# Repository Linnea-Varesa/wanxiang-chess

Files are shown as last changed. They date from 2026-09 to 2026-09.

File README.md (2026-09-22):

> **当前执行基线（2026-09-22）**：第一阶段直接做 3×3 九线圈识别验证。第一批一次采购完整 3×3 所需器件，霍尔先买 3～4 个做位置层对照；验证按单线圈→三线圈→九线圈推进，M3 截止 2026-10-31。8×8 材料待 M3 通过后决定。

# 万象实体互动桌：国际象棋路线

当前版本正在从“触点身份棋盘”调整为“无触点静态识别优先”的原型：棋子底部优先测试无电池被动身份标签，棋盘表面保持平滑，通过小规模样片验证身份和格位。ESP32-S3 负责设备控制、快照、屏幕和通信，手机或后续微信小程序负责棋局、合法性、本地 AI 和语音指导。DS2431G/GA + 触点保留为电气基线和备用路线。自动移子只预留接口，今年不做实物交付。

摄像头识别、64 格 RFID 阵列、自动移子和量产结构不属于当前验收范围。

本目录是新方向的正式工程目录。目标是用一年时间，由两人小组（每人每周约 6 小时）完成一台个人可稳定使用的国际象棋实体互动桌，并在稳定性、成本和安全性达到要求后评估小规模量产。

## 当前冻结的首年范围

- 国际象棋，8×8 棋盘，Android 优先。
- 首版先完成：棋子唯一身份、静态格位识别、平滑棋盘、棋局状态、BLE 同步、AI 走法和语音/屏幕提示。
- 先用玩家手动放置验证识别；系统必须能用 UID 和格位复核结果。
- 自动移动、让路和多棋子同步只保留机械接口与研究记录，不列入 2026 年交付。
- Android 仅作为当前工程调试端；微信小程序保留为后期交互候选，协议不绑定某一种前端。
- 首批实验预算约 2000–3000 元。已有万用表、焊接工具、可调电源和基础机械工具，不重复采购。

## 资料边界

[`references/original_handoff/`](references/original_handoff/) 和 [`references/original_archive/`](references/original_archive/) 是历史交接资料和原始压缩包的只读参考副本。原工程第一版以五子棋、摄像头 ArUco 和单 XY 演示为主；新工程以本 README 和 [`docs/`](docs/) 中的决策为准。

完整目录用途和文件路径索引见 [`docs/18_目录与文件索引.md`](docs/18_目录与文件索引.md)。当前硬件决策以 [`docs/25_工程重整与一次性采购决策_2026-09-22.md`](docs/25_工程重整与一次性采购决策_2026-09-22.md) 为准。文档之间的引用使用相对于引用文件的路径；历史参考副本保留原路径，不作为当前工程接口。

面向指导老师的当前阶段汇报、采购、分工和周计划集中在 [`teacher_report/`](teacher_report/)，首份总览为 [`teacher_report/00_阶段汇报_2026-09-18.md`](teacher_report/00_阶段汇报_2026-09-18.md)。

## 先做什么

1. 根据 [`mechanical/pieces/3mf模型核验_2026-09-18.md`](mechanical/pieces/3mf模型核验_2026-09-18.md) 先打印少量兵、马、车，测量底座和身份盘空间。
2. 用第一批九路线圈、PN5180、SLIX2 标签和 3×3 非金属面板做身份、相邻格隔离和读距验证；先接单线圈，再扩三线圈和九线圈。
3. 同步搭建与前端无关的规则模拟器和 BLE 协议，不等待全盘硬件。
4. 形成“识别 → 合法走法 → AI → 语音/屏幕 → 玩家手动移动 → 复核”的闭环。
5. 识别稳定后，再为后续自动移子保留机械和通信接口，不在今年采购完整运动机构。

## 文档索引

- [`docs/01_项目目标与范围.md`](docs/01_项目目标与范围.md)
- [`docs/02_一年路线图与阶段验收.md`](docs/02_一年路线图与阶段验收.md)
- [`docs/03_工作分解与两人分工.md`](docs/03_工作分解与两人分工.md)
- [`docs/04_系统架构与接口.md`](docs/04_系统架构与接口.md)
- [`docs/05_棋子身份识别实验.md`](docs/05_棋子身份识别实验.md)
- [`docs/06_嘉立创EDA与电路计划.md`](docs/06_嘉立创EDA与电路计划.md)
- [`docs/07_固件开发计划.md`](docs/07_固件开发计划.md)
- [`docs/08_Android与AI计划.md`](docs/08_Android与AI计划.md)
- [`docs/09_自动移子与避障研究.md`](docs/09_自动移子与避障研究.md)
- [`docs/10_预算采购与风险.md`](docs/10_预算采购与风险.md)
- [`docs/11_量产前准备.md`](docs/11_量产前准备.md)
- [`docs/12_资料索引与决策记录.md`](docs/12_资料索引与决策记录.md)
- [`docs/13_三个月无视觉身份棋盘方案.md`](docs/13_三个月无视觉身份棋盘方案.md)
- [`docs/14_开发板与器件选型核验.md`](docs/14_开发板与器件选型核验.md)
- [`docs/15_参考产品说明书分析.md`](docs/15_参考产品说明书分析.md)
- [`docs/16_触点对自动移子影响与身份器件决策.md`](docs/16_触点对自动移子影响与身份器件决策.md)
- [`docs/17_开发板选择与系统分层.md`](docs/17_开发板选择与系统分层.md)
- [`docs/18_目录与文件索引.md`](docs/18_目录与文件索引.md)
- [`docs/19_无触点身份与自行移动路线评估.md`](docs/19_无触点身份与自行移动路线评估.md)
- [`docs/20_屏幕与微信小程序后置方案.md`](docs/20_屏幕与微信小程序后置方案.md)
- [`docs/22_3x3识别定位试验BOM评审_2026-09-20.md`](docs/22_3x3识别定位试验BOM评审_2026-09-20.md)

## 状态约定

文档中的“计划”不是“已验证”。每项工作必须记录负责人、日期、实测数据、结论和下一步。首年不把零碎时间计入承诺产能。

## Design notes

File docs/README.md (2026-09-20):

# 文档目录

本目录保存项目决策、技术方案、路线、采购核验和参考产品分析。总目录见 [`18_目录与文件索引.md`](18_目录与文件索引.md)；当前无视觉主线见 [`13_三个月无视觉身份棋盘方案.md`](13_三个月无视觉身份棋盘方案.md)；新提交的 3×3 识别定位 BOM 评审见 [`22_3x3识别定位试验BOM评审_2026-09-20.md`](22_3x3识别定位试验BOM评审_2026-09-20.md)。

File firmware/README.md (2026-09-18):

# ESP32-S3 固件

PlatformIO 工程，运行在棋盘主控上。编译配置见 [`platformio.ini`](platformio.ini)，源码见 [`src/`](src/)，身份扫描入口见 [`src/identity_grid.cpp`](src/identity_grid.cpp)。

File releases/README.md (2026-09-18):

# 发布与演示包

预留 Android APK、ESP32 固件 bin、演示脚本、录屏和版本归档。当前尚未生成正式发布包。

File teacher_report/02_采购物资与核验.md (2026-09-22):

# 采购物资与参数核验（当前版）

时间 tag：`2026-09-22T21:00+08:00`

## 采购决定

今天下单第一批完整 3×3 九线圈验证系统。器材一次采购到位，安装和验证按单线圈、三线圈、九线圈分阶段执行。目标是 2026-10-31 前完成 M3 九线圈静态快照；3×3 通过后才决定 8×8 全棋盘材料。

## 第一批采购

| 模块 | 型号/规格 | 数量 | 用途 | 核验重点 |
|---|---|---:|---|---|
| 主控 | ESP32-S3-DevKitC-1-N8R8 或可靠 N16R8 | 1+1备用 | 扫描调度、显示、USB/BLE | 丝印、GPIO、USB、3.3 V |
| 读卡 | PN5180 成品开发板 | 1 | 读取 ISO15693 标签 UID | SPI、外接天线/匹配接口 |
| 棋格线圈 | ANT-24-V1 | 9+1备用 | 九个格位采样 | 电感、Q、谐振和邻格耦合 |
| RF切换 | RF-SW-9CH-V1 | 1 | 把一个读头逐格接到九线圈 | 是否已经装 9 个 RF 继电器、是否双线 DPDT |
| RF继电器 | G6K-2F-RF-V DC5 | 9（仅切换板不含时购买） | 切换 PN5180 两条 RF 线 | 完整后缀、线圈电压、触点形式 |
| 继电器控制 | SN74HC595PWR + ULN2803CDWR | 各2 | 输出选择位和驱动 5 V 继电器 | 3.3 V 输入吸合测试 |
| 霍尔位置层 | DRV5032 + D6×2 mm 磁铁 | 3～4 + 6～8 | 验证有/无棋子，不识别身份 | 感应距离、输出类型、去抖 |
| 霍尔输入扩展 | SN74HC165PWR | 2 | 9 路霍尔预留输入 | 串行位序、上拉和电平 |
| 棋子身份 | ISO15693 SLIX2 小标签 | 12～15 | 9 枚使用，余量备用 | 优先 12～16 mm；读距和磁体影响 |
| 显示 | ST7789 2 inch SPI | 1+1备用 | 现场显示通道、UID、状态 | 实物引脚和逻辑电平 |
| 电源/匹配/连接 | 5 V 4 A、3.3 V模块、C0G电容、电阻、U.FL、短同轴、非金属面板、端子 | 1套 | 供电、调谐和搭建 | 共地、反灌、RF走线 |
| 测量 | NanoVNA-H4 | 1或借用 | 测谐振、匹配、串扰 | 校准夹具和重复性 |

## 分阶段验证

- **M0（9月27日前）**：所有第一批物料到货清点，完成丝印、接口、电源和缺件记录。
- **M1（10月4日前）**：单标签和单线圈连续读取，屏幕和电脑网页显示日志。
- **M2（10月18日前）**：三线圈逐格读取，3～4 路霍尔与 UID 结果对照。
- **M3（10月31日前）**：九线圈安装完成，重复采集 3×3 静态快照，记录空读、串读、成功率和扫描耗时。

阶段门只控制“如何接入和验证”，不再触发第二次 3×3 架构采购。M3 后再决定 8×8 材料。

详细清单见 [`../hardware/bom/3x3首批一次采购清单_2026-09-22.md`](../hardware/bom/3x3首批一次采购清单_2026-09-22.md)。

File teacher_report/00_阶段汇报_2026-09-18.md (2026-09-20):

# 万象实体互动桌阶段汇报

**时间 tag：`2026-09-18T18:45+08:00`**
**汇报周期：`2026-09-19` 至 `2026-12-31`**  
**项目类型：两人个人学习与娱乐原型，国际象棋，Android 优先**

## 一、目前进度

项目已经从“空想和资料收集”进入“识别路线重新评估、采购准备、首个 3D 打印测试待启动”阶段。当前已经完成：

- 在 `F:/projects/wanxiang-chess` 建立正式工程目录、目录说明和相对路径索引。
- 阅读并保存参考产品说明书、历史交接文件和原始工程；历史资料仅作参考。
- 启动路线修正：不采用视觉识别作为主链路，优先验证平滑棋盘、被动身份标签和静态格位识别；原 `DS2431G/GA + 触点` 方案降为电气基线。
- 保留 `ESP32-S3` 作为主控，负责读头、快照、屏幕和 BLE；自动移子状态机只预留接口，前端不绑定 Android，微信小程序保留为后置候选。
- 已读取用户提供的 `chess.3mf`，确认其棋盘插板约 204×204×3 mm，平均格距约 25.5 mm，棋子底座约 17.85–21.41 mm。
- 建立固件身份扫描原型、身份记录格式、2×2/4×4 实验方案、采购清单和三个月验收清单。
- 已补充具体采购检索：ESP32-S3-N16R8 预焊针版、PN532 V3、ILI9341 屏幕、3 mm 亚克力样片、N42 圆片磁体和 5 V 3 A 电源；检索词与验收条件见 [`../hardware/bom/采购检索与核验_2026-09-20.md`](../hardware/bom/采购检索与核验_2026-09-20.md)。
- 已有基础工具：万用表、焊接工具、可调电源和基础机械工具。

尚未完成且不应在汇报中表述为已完成：

- 没有真实开发板、标签/读头样品或 DS2431 接触座上的电气验证。
- 没有 2×2 或 4×4 实物识别成功率数据。
- ESP32 固件尚未在真实板卡上编译烧录。
- Android 尚未形成可安装 APK，BLE 仍处于协议和模型准备阶段。
- 8×8 全盘身份阵列、自动移子、多棋子让路和量产结构均未立项实现。

## 二、项目方向

目标是做一台个人使用的实体国际象棋互动桌：棋子本身不带电池、不放蓝牙模块和复杂电路板；棋子底部使用被动身份标签，棋盘表面保持平滑，先由小规模样片验证“哪个格位出现哪个 UID”。主控负责快照、屏幕和通信，后续由 Android 或微信小程序负责棋局和 AI。

产品闭环为：

```text
棋子 UID/格位样片 → 读头/位置层 → ESP32-S3 → BLE/屏幕
→ 合法性判断/AI/难度/语音 → 玩家手动放置 → 再次扫描确认
```

首版重点是证明“无电池棋子在平滑棋盘上能被稳定识别并定位”。自动移子不在 2026 年范围内，运动机构只保留接口和后续研究记录。

## 三、预计技术方案

### 1. 棋子身份

当前首选先测试 13.56 MHz、ISO14443A 的 `NTAG213` 小标签；它不需要电池，UID 可作为棋子身份。`DS2431G+U/GA+U` 与触点保留为静止棋子电气基线，因为触点会增加滑动阻力、磨损和落位约束。

先按 `chess.3mf` 打印兵、马、车各 1–2 枚，底部使用可更换身份盘。先比较空白盘、NFC 标签盘和磁编码盘，再决定是否改永久结构。

### 2. 棋盘主控和识别

首选 `ESP32-S3-DevKitC-1-N8R8` 两块，一主一备。它负责 NFC/位置层读头、快照、BLE 和屏幕接口；AI 不放在 ESP32 上。首轮只做 2×2 无触点样片。

### 3. 软件和屏幕

Android 先作为调试端；微信小程序保留为后期交互候选。两者都不直接绑定硬件，先共用 BLE/串口消息协议。棋盘加入 2.8 inch ILI9341 SPI 屏幕，显示回合、走法、连接、扫描和故障状态；AI 仍在手机/电脑运行。

### 4. 自动移子后续边界

主路线不使用暴露触点。棋盘表面保持平滑，自动移子将来可采用下方磁力耦合，但 2026 年不采购、不搭建实物运动机构；多棋子同步、让路和避障列为后续研究。

## 四、截至年底的目标

年底目标是一个可向老师演示的“识别与软件闭环原型”，而不是完整量产产品：

- 硬件：完成 3D 打印棋子样品、单枚被动标签识别、2×2 无触点定位样片，争取扩展到 4×4；屏幕由 ESP32-S3 驱动显示基本状态。
- 软件：完成棋子 UID 登记、棋局模型、BLE 快照协议、Android 棋盘视图、AI 走法、至少 3 档难度和语音提示。
- 演示：从局面加载开始，完成“AI 指定走法 → 屏幕/语音提示 → 玩家手动放置 → UID/位置确认 → 继续对局”，并演示一次放错棋子或格位的错误提示。
- 文档：保留采购凭证、接线图、UID 登记表、实验数据、问题清单和每周总结。

不列入年底硬性承诺：8×8 实物全盘、多个棋子同时移动、联网对战、量产设计和最终外壳。

## 五、主要风险和判断点

1. **标签读距和相邻格串读**：先用 2×2 数据判断是否继续扩大；不能只凭一次读到 UID 就认为方案可行。
2. **磁力与身份件互扰**：先测 NFC 标签、磁体和读头距离，再决定底部结构。
3. **3D 打印尺寸误差**：先打印兵、马、车各少量样品，测量底面和格距，不直接批量加工。
4. **软件和硬件进度不同步**：Android 规则模拟器先用固定快照开发，不等待完整棋盘。
5. **每周只有 12 人时**：每周只承诺一个主交付物，零碎时间用于补充，不把不确定的自动机械纳入年底主线。

## 六、教师汇报时的结论

本项目目前最需要老师关注的是“无电池棋子身份标签能否在平滑棋盘下稳定识别并正确归属到格位”。因此下一步先打印少量棋子，采购少量标签和 NFC 读头样品，拿到读距、串读和定位数据，再决定是否进入 4×4、8×8 和后续运动机构阶段。

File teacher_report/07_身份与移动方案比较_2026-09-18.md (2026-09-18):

# 身份与移动方案比较

**时间 tag：`2026-09-18T19:20+08:00`**

## 结论

触点方案适合先做“静止棋子识别”，但不适合作为“棋子在平滑棋盘上自行移动”的默认结构。原因不是读不出 UID，而是棋子移动时会遇到触点摩擦、卡滞、接触磨损和落位限制；若采用抬起再放下，又会把核心机构变成夹持/搬运。

当前采购和验证顺序改为：

1. 用 `chess.3mf` 打印兵、马、车各少量样品；
2. 用 `NTAG213` 小标签验证无电池 UID 和 3 mm 板下读距；
3. 用 4/6/8 mm、2–3 mm 厚 NdFeB 磁体验证下方磁力驱动；
4. 用 PN532 作为标签 UID/读距基准，不把模块天线尺寸当成最终方案；
5. 用 2×2 平滑非金属样片测试相邻格串读；
6. 以上通过后再决定运动台架、线圈尺寸和 8×8 结构。

## 采购确认

**现在可买：** ESP32-S3 两块、3D 打印棋子、NTAG213 小标签、PN532 样品、几种尺寸磁体、2×2 非金属板材料、基本接线和可选 ILI9341 屏幕。

**暂缓：** DS2431/DS2401、74HC4067、40 个弹簧针、4×4 触点板、整盘 RFID、步进电机和导轨。触点物料不是永久取消，而是等无触点主路线出现读距或抗干扰问题时作为回退。

## 关键测量记录

每个样品必须记录：棋子底座直径、底面平整度、身份盘厚度、标签读距、相邻格串读、磁力吸附力、移动停位误差、磁体与标签的距离、读取耗时和失败原因。没有这些数据前，不批量修改 32 枚棋子或加工整盘棋盘。

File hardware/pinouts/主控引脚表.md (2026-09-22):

# ESP32-S3 主控引脚表（PN5180 3×3 当前方案）

时间 tag：2026-09-22

> 这是“逻辑分配表”，不是最终焊接图。ESP32-S3-DevKitC-1-N8R8 到货后，必须按实物丝印和原理图复核。旧 PN532/ILI9341/运动机构引脚表已不再作为当前方案依据。

## 推荐接口分配

| 功能 | GPIO | 说明 |
|---|---:|---|
| PN5180 SCK/MOSI/MISO | 12/11/13 | 与其他 SPI 设备共用总线 |
| PN5180 CS | 10 | 独立片选 |
| PN5180 BUSY | 9 | 输入 |
| PN5180 RST/ NSS辅助 | 8 | 输出，按模块接口确认 |
| ST7789 CS/DC/RST | 14/15/16 | 屏幕片选、数据命令、复位 |
| ST7789 BL | 17 | 可先固定高电平，确认背光电流后再 PWM |
| 74HC595 DATA/CLK/LATCH | 4/5/6 | 控制九路继电器；两个 595 串联使用 |
| 74HC165 DATA/CLK/LOAD | 7/18/19 | 读取霍尔输入扩展；两个 165 可串联 |
| 霍尔中断/状态预留 | 20 | 可选，不接时保留 |
| 调试/扩展 UART | 43/44 | 仅在板卡引出且不影响 USB 时使用 |
| USB | 板载 USB | 下载、日志、网页监视器 |

## 接口余量结论

- 9 个霍尔不需要 9 个 ESP32 GPIO：用两个 74HC165 串行读取，实际只占 3 个控制/数据 GPIO。
- 9 个继电器不需要 9 个 ESP32 GPIO：用两个 74HC595 串行输出，实际只占 3 个控制 GPIO。
- PN5180 与 ST7789 可以共用 SPI 的 SCK/MOSI/MISO，但必须使用独立 CS，且 PN5180 的 BUSY/RST 单独连接。
- 因此“霍尔 + PN5180”在接口数量上可行；真正的风险是射频、供电、引脚电平和板卡实际引出情况。

## 电平和供电

ESP32、PN5180 逻辑、ST7789 逻辑、595/165 共用 3.3 V 逻辑和 GND。5 V 只给 5 V 继电器线圈或明确支持 5 V 的模块；不能把 5 V 直接送入 ESP32 GPIO。ULN2803 或逻辑电平 MOSFET 负责继电器线圈低端驱动。

## 到货复核

1. 拍摄开发板正反面，记录模组丝印和所有已占用引脚。
2. 用万用表确认 3.3 V、5 V、GND 和 USB 供电路径。
3. 单独验证 PN5180 SPI，再接 ST7789。
4. 先接 1 个 595 输出和 1 个 165 输入，再扩展到 9 路。

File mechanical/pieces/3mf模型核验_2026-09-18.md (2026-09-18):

# 3MF 棋子模型核验

**时间 tag：`2026-09-18T18:40+08:00`**  
**源文件：** [`../../chess.3mf`](../../chess.3mf)

## 文件结论

该 3MF 是 BambuStudio 项目，包含国际象棋棋子、棋盘盒体和棋盘插板，不是单独的一枚棋子文件。模型元数据使用毫米单位，切片配置为约 0.20 mm 层高、2 层墙、10% 填充；这些打印参数可作为初始参考，功能验证时应提高棋子底部强度。

## 从模型网格读取的包围盒

| 对象 | 包围盒约值（X×Y×Z，mm） | 工程意义 |
|---|---:|---|
| 棋盘盒体 | 208×206×31 | 当前模型整体尺寸 |
| 棋盘插板 | 204×204×3 | 8×8 时平均格距约 25.5 mm；适合先做同尺寸小样片 |
| 兵 | 17.85×17.85×29.51 | 底部空间最紧，优先测试 |
| 象 | 19.54×19.55×42.93 | 可作为第二种高度样品 |
| 马 | 20.33×20.33×34.65 | 需要注意头部方向与底部平整度 |
| 车 | 20.49×20.80×39.07 | 适合测试标签盘和磁体盘 |
| 后 | 21.34×21.34×45.56 | 底座略大 |
| 王 | 21.41×21.41×55.09 | 高度最大，后续测试稳定性 |

## 对身份和移动的影响

- 当前格距约 25.5 mm，不能继续使用原采购表中 35–40 mm 的样片假设；
- 17.85–21.41 mm 的棋子底座可以容纳小型 13–16 mm 被动标签，但必须实测标签外径、粘贴余量和磁体位置；
- 不建议直接在现有模型上批量埋入 DS2431 或磁体。先打印兵、马、车各 1–2 枚，测量底面厚度后再开身份盘；
- 棋盘插板厚度约 3 mm，对 13.56 MHz 读距是有利条件，但若加入金属薄片、钢垫或强磁体，必须重新测试天线调谐和读距；
- 若采用下方磁力驱动，棋子底面要尽量平滑，不能保留会刮擦棋盘的凸起触点。

## 第一批打印建议

先打印 3 类：兵、马、车。每类至少 2 枚：一枚保持原模型用于尺寸基准，一枚预留可拆底盖或身份盘。底盖优先做成可更换件，便于比较 NFC 标签、磁编码和空白配重，不要直接修改整套棋子。

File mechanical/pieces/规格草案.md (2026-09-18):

# 棋子底部身份组件规格草案

## 首版目标

以 [`3mf模型核验_2026-09-18.md`](3mf模型核验_2026-09-18.md) 中的 3D 打印棋子为基础，优先做可更换的底盖/身份盘。当前主路线不在棋子底部设置凸起触点，而是测试被动 NFC 标签、磁编码盘和磁力耦合件；DS2431G/GA + 触点只保留为电气基线。首轮只打印兵、马、车各 1–2 枚，不加工 32 枚全套。

## 建议结构

- 棋子底座直径：3MF 网格约为 17.85–21.41 mm；打印后实测底平面和内部可用高度。
- 被动身份件候选：13–16 mm、13.56 MHz、ISO14443A 的 NTAG213 小标签；优先选择可拆换、非金属封装。
- 磁力耦合件候选：直径 6 mm、厚 2 mm 的 NdFeB N35/N42 圆片；先验证与标签、棋盘和磁力滑台的干扰。
- 底盖/身份盘：优先可更换，避免第一次打印就永久封装器件。
- 芯片周围使用可更换绝缘压框，压框损坏时可以换，不把器件灌死在环氧树脂中。
- 若增加磁铁辅助霍尔传感器，磁铁与芯片保持塑料隔层；芯片不需要磁场供电。

## 不采用的结构

- 不在棋子底部放大面积金属片或钢垫片，避免 NFC 天线失谐、磁传感器饱和和磁力滑台吸附异常。
- 被动标签 UID、身份盘类型和对局当前角色仍要在 [`../../software/controller/models.py`](../../software/controller/models.py) 中分开建模。
- 如果回退到 DS2431，EEPROM 初始字段仍按 [`../../software/protocol/piece_identity_record.md`](../../software/protocol/piece_identity_record.md) 管理。
- 不在第一版给每枚棋子安装电池、蓝牙或主动发射器。

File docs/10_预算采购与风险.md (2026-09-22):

> **当前路线修订（2026-09-22）**：当前执行以 `docs/25_工程重整与一次性采购决策_2026-09-22.md`、`hardware/bom/3x3首批一次采购清单_2026-09-22.md` 和 `teacher_report/plans_2026-10_12/万象实体互动桌_10-12月计划与3x3执行表_2026-09-22.xlsx` 为准。第一批一次采购完整 3×3 九线圈验证系统；本文件中仍写“2×2/分批采购”的内容属于历史讨论。

# 10 预算、采购与风险

## 三个月采购决策

三个月主线更新为无视觉、无触点静态识别验证：ESP32-S3 + 被动 NTAG213/磁编码候选 + 小型读头/位置层 + BLE。DS2431G/GA + 触点降为静止棋子电气基线；64 格 RFID、摄像头、整盘 PCB 和自动移子均后置。

## 首批预算分配

已有基本仪器，不重复采购。2000–3000 元先用于能否行通的实验，不用于一次性购买整套全盘零件。首批不把最终 32 枚棋子、标签或运动件全部买齐，先用样品验证尺寸、读距、串读和静态定位。

| 类别 | 预算 |
|---|---:|
| ESP32-S3 开发板、稳压、连接器和线材 | 250–350 元 |
| 打印棋子、被动标签、NFC 读头和磁体样片 | 300–650 元 |
| 2×2 平滑样片、结构件和小面积电路实验 | 200–400 元 |
| 小面积 PCB、打样和耗材 | 250–450 元 |
| 扬声器、功放和音频件 | 100–200 元 |
| 屏幕、调试备件和后置传感器 | 100–250 元 |
| 返工与追加实验预留 | 400–600 元 |
| 合计 | 1630–2750 元 |

若识别实验失败，停止扩大全盘采购，先切换后备路线。采购分三批：识别样片、通信/规则闭环、结构与运动件。

## 风险登记

| 风险 | 等级 | 触发条件 | 应对 |
|---|---:|---|---|
| UID 能读但格位不确定 | P0 | 单读头盘点无法定位 | 用滑台坐标或 2×2 读头隔离；失败则保留触点基线 |
| 标签读距不足/相邻格串读 | P0 | 3 mm 板下读不到或同时读到邻格 | 调整线圈、标签尺寸、棋盘厚度和扫描时序 |
| 未来磁力机构与身份件互扰 | P1 | 磁体使 NFC 失谐或传感器饱和 | 今年只做少量材料对照，后续分离驱动/读取时刻 |
| 两人实际人时不足 | P0 | 连续两周无可检查输出 | 缩减 4×4 和前端范围，保住静态 V1 |
| 手机 AI 性能不足 | P1 | 思考时间过长/耗电 | 调低预算，转可选联网或运算板 |
| BLE 断线造成状态错乱 | P1 | 增量事件丢失 | 版本号、完整快照和重同步 |
| 机械让路失败 | P0 | 路径穿不过密集棋子 | 临时停车、绕行、顺序执行 |
| 固件限位失效 | P0 | 回零不停止或撞击 | 硬限位、超时、限流、STOP |
| 量产成本超标 | P2 | BOM 超预算或装配复杂 | 先完成个人样机，再做可制造性评估 |

## 量产前不得提前承诺

全盘识别成本、稳定移动寿命、噪声、温升、跌落/运输、EMC、材料安全和许可证义务都没有数据前，不能承诺固定售价或量产时间。

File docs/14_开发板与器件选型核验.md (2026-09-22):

> **当前路线修订（2026-09-22）**：当前执行以 `docs/25_工程重整与一次性采购决策_2026-09-22.md`、`hardware/bom/3x3首批一次采购清单_2026-09-22.md` 和 `teacher_report/plans_2026-10_12/万象实体互动桌_10-12月计划与3x3执行表_2026-09-22.xlsx` 为准。第一批一次采购完整 3×3 九线圈验证系统；本文件中仍写“2×2/分批采购”的内容属于历史讨论。

# 14 开发板与器件选型核验

> **路线更新（2026-09-20）**：本文件中 DS2431/DS2401、74HC4067 和触点条目保留为电气基线。当前采购优先级以 [`../teacher_report/02_采购物资与核验.md`](../teacher_report/02_采购物资与核验.md) 和 [`../hardware/bom/采购检索与核验_2026-09-20.md`](../hardware/bom/采购检索与核验_2026-09-20.md) 为准，先验证 3D 打印棋子、NTAG213、PN532、2×2 亚克力样片和屏幕。

## 主控

| 器件 | 建议型号 | 必须满足的参数 | 结论 |
|---|---|---|---|
| BLE 主控 | 优先 ESP32-S3-WROOM-1-N16R8 开发板（截图中的“ESP32-S3-N16R8 焊针 + Type-C 数据线”）；买不到可靠 N16R8 时选官方 ESP32-S3-DevKitC-1-N8R8 | 3.3 V GPIO、BLE 5、至少 8 MB Flash、至少 8 MB PSRAM、USB 数据下载；必须能提供引脚图 | 首批买 2 块，选预焊针版本；不选 C3，不选只带 OLED/TFT 的不明套装 |
| 多路选择 | 74HC4067 模块/芯片 | 16 路双向模拟开关，2–6 V 供电，导通电阻尽量低 | 触点回退实验再买，不属于无触点首批 |
| 身份芯片（回退） | DS2431G+U / DS2431GA+U | 1-Wire 64-bit ROM + 1 kbit EEPROM；无电池；SFN 机械接触封装 | 无触点路线失败或需要对照时买少量 |
| 身份芯片（回退） | DS2401+ TO-92 | 1-Wire 64-bit 唯一 ROM、2.8–6 V；只能提供 UID，无用户 EEPROM | 只作低风险电气备份，不作为当前主线 |
| 触点（回退） | 2–3 mm 弹簧针或镀金铜触点 | 每格两触点，能承受反复放置，接触电阻稳定 | 触点基线实验再买，不做平滑棋盘主接口 |
| 上拉/保护 | 4.7 kΩ、2.2 kΩ、100 Ω 电阻；TVS 可后置 | 3.3 V 逻辑和台架保护 | 电阻包可与首批接线一起买 |

## 可选辅助器件

| 器件 | 建议型号 | 用途 | 结论 |
|---|---|---|---|
| 霍尔开关 | DRV5033 3.3 V 版本模块或裸件 | 判断抬起/落下，辅助去抖和故障提示 | 买 8 个做 2×4 实验，非身份主链路 |
| 磁体 | 直径 4–6 mm、厚 2–3 mm 的小磁铁 | 配合霍尔传感器 | 少量购买，与身份芯片触点分层安装 |
| 逻辑分析仪 | 8 通道 USB 逻辑分析仪 | 看 1-Wire 波形、BLE 外不需要 | 已有则不买，没有再买低价款 |
| 电源 | 台架先用现有可调电源；成品电源选固定 5 V 3 A、带过流/短路保护的适配器；必要时增加 5 V→3.3 V 1 A DC-DC | 主控、读头和屏幕供电；今年不接电机 | 不把 12 V 或未标额定电压的电源接到 ESP32/屏幕 |

## 当前可采购的非触点实验件

| 器件 | 结论 | 使用边界 |
|---|---|---|
| PN532 V3 | 可以购买 1 块 | 只用于 NTAG213 UID、读距和读场范围基准；优先 I2C 接 ESP32，SPI 留给屏幕；必须确认信号为 3.3 V 或有可靠电平转换 |
| 2×2 样片 | 不买所谓“成品阵列”，自行制作 | 3 mm 透明亚克力/PC 板，100×100 mm，2×2 方格边长 25.5 mm；不用金属板、铜箔或 FR4 |
| ILI9341 屏幕 | 可以购买独立 2.8 英寸 SPI 模块；截图中的 2.8 英寸套装只有在卖家确认驱动 IC 后才可买 | 240×320、ILI9341、3.3 V 逻辑；触摸和 SD 首轮不接 |

PN532 V3 的板载天线通常大于一个 25.5 mm 棋盘格。因此它读到单标签并不证明 2×2 或 8×8 定位可行；若在相邻格也能读到，记录为读场过宽，后续需要小线圈或位置层。

## 明确不列入首批

- 64 个 RFID 读头、64 格定制天线、整盘 PCB：先有 2×2/4×4 数据再决定。
- A3144：常见版本要求 4.5 V 以上，不能直接按 3.3 V ESP32 设计；用 DRV5033 3.3 V 版本替代。
- 步进电机、导轨、电磁铁、树莓派、云服务器：2026 年不采购，后续自动移子立项时再决定。

器件身份和封装依据见 [`docs/16_触点对自动移子影响与身份器件决策.md`](16_触点对自动移子影响与身份器件决策.md)，主控分层和引脚核对见 [`docs/17_开发板选择与系统分层.md`](17_开发板选择与系统分层.md)。

## 建议首批采购金额

| 类别 | 预算 |
|---|---:|
| ESP32-S3 两块 | 80–180 元 |
| PN532 V3、NTAG213 少量标签 | 60–140 元 |
| 3 mm 亚克力/PC 样片、棋子和底部加工材料 | 80–250 元 |
| ILI9341 屏幕 | 35–80 元 |
| 接线、电阻、排针、杜邦/JST | 80–180 元 |
| 磁体和可选 5 V 电源 | 0–140 元（台架先复用已有可调电源） |
| 返工预留 | 300–500 元 |
| **首批合计** | **约 635–1,470 元，不含打印渠道差异** |

已有手机、电脑、万用表、焊接工具、可调电源和基础机械工具不重复计入。剩余预算等 2×2/4×4 读数稳定后再决定是否购买小线圈、位置层和 8×8 材料。DS2431 的具体机械约束和写入流程见 [`docs/16_触点对自动移子影响与身份器件决策.md`](16_触点对自动移子影响与身份器件决策.md)。

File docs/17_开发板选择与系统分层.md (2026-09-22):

> **当前路线修订（2026-09-22）**：当前执行以 `docs/25_工程重整与一次性采购决策_2026-09-22.md`、`hardware/bom/3x3首批一次采购清单_2026-09-22.md` 和 `teacher_report/plans_2026-10_12/万象实体互动桌_10-12月计划与3x3执行表_2026-09-22.xlsx` 为准。第一批一次采购完整 3×3 九线圈验证系统；本文件中仍写“2×2/分批采购”的内容属于历史讨论。

# 17 开发板选择与系统分层

## 当前推荐组合

> **路线更新（2026-09-18）**：ESP32-S3 仍作为主控，但感知主链路不再默认使用 DS2431 触点。当前先验证被动 NFC/磁编码与静态位置层；DS2431/74HC4067 留作电气基线，自动移子顺延。详细取舍见 [`19_无触点身份与自行移动路线评估.md`](19_无触点身份与自行移动路线评估.md)。

### 棋盘主控：ESP32-S3-DevKitC-1-N8R8

首批建议购买 2 块同型号开发板，1 块主用、1 块备份。选择理由：

- 原生 BLE 5，直接满足 Android 通信，不需要额外蓝牙模块；
- 3.3 V GPIO，适合 DS2431/DS2401、74HC4067、霍尔传感器和状态灯；
- USB 下载和串口调试方便，适合当前两人学习开发；
- 8 MB Flash/8 MB PSRAM 版本给日志、协议和后续音频接口留余量；
- 当前仓库已有 PlatformIO 工程目标 `esp32-s3-devkitc-1`，迁移成本低。

这块开发板是“棋盘主控”，不是 AI 主机。ESP32-S3 负责读头/传感器扫描、磁力运动状态机、屏幕和 BLE；AI 先在调试端或后续微信小程序/Android 端运行。

`N8R8` 是优先选项，不是必须条件；识别固件本身不需要 PSRAM。如果实际购买的开发板是 N8、N4、WROOM-1 或其他 ESP32-S3 板，必须先记录准确丝印、Flash/PSRAM 型号和引脚图，再修改 [`firmware/src/config.h`](../firmware/src/config.h) 与 [`hardware/pinouts/主控引脚表.md`](../hardware/pinouts/主控引脚表.md)。

### 不建议首批使用的主控

- **ESP32-C3**：BLE 足够，但 GPIO 和资源余量较小；只有预算非常紧或已有现货才考虑。
- **ESP32-WROOM-32**：BLE 可用，但当前仓库和后续资源优先按 S3 维护；不为换板增加变量。
- **树莓派/国产 Linux 板**：对 1-Wire 和 BLE 不是不能做，但会增加系统、存储、启动和供电复杂度；AI 放在 Android，暂不需要。
- **Arduino Uno/ESP8266**：不适合作为 Android BLE 主控。

## 主控分工

首版不要拆成多个控制模块。一个 ESP32-S3 足以负责：

1. 触点扫描和 DS2431/DS2401 ROM 读取；
2. 识别去抖、快照和错误状态；
3. BLE GATT 服务；
4. 后续单 XY 电机/电磁铁的运动接口。

只有在 8×8 扫描周期、运动实时性或隔离测试证明一个主控不够时，才考虑把运动控制拆成第二块 MCU。多个模块不会自动解决“多个棋子同时移动”的机械问题。

## 识别接口建议

- 当前主线：下方移动读头读取被动 `NTAG213` UID，滑台坐标提供格位；首轮只做 2×2。
- 备选主线：每格磁传感器读取磁编码；驱动磁场关闭后再采样。
- 电气基线：1 个 `74HC4067` + DS2431/DS2401 触点实验，不作为自行移动产品默认表面接口。

- NFC 读头：首轮使用 1 个带 I2C/SPI 的 PN532 类模块和小尺寸外部线圈做读距实验；最终读头型号在 2×2 读距数据后确定；
- 运动接口：首轮只记录未来磁力耦合件的尺寸、电源和状态字段，不采购滑台；
- 电气基线：1 个 74HC4067 做 4×4 触点实验；不先扩展 64 格；
- 屏幕：预留 SPI 总线给 2.8 inch ILI9341，实际 GPIO 等开发板到手后核对；
- 协议：复用 [`software/protocol/message_schema.md`](../software/protocol/message_schema.md) 和 [`software/protocol/test_vectors.md`](../software/protocol/test_vectors.md)。

## 需要立即修正的工程认识

`DS2431G/GA` 是“唯一 ID + 小容量 EEPROM”器件，适合把初始棋子信息预写到棋子中；`DS2401+` 只有工厂 UID，保留为电气原型备选。无论使用哪一种，Android 都要维护 UID、角色和对局状态的独立数据。

## 开发板采购判定

采购页面必须同时满足：

- 芯片确实为 ESP32-S3，而不是 ESP32-C3/ESP32；
- 板载 USB 可下载和串口日志；
- 引出 GPIO5–10 或有等价可用引脚；
- 3.3 V、GND、5 V/VBUS 标注明确；
- 标出 Flash/PSRAM 配置；
- 有可核对的板卡原理图或引脚图。

如果商品只写“ESP32-S3 开发板”而没有具体模组和引脚图，不作为首选采购。

本文档引用的首版身份协议见 [`../software/protocol/piece_identity_record.md`](../software/protocol/piece_identity_record.md)。

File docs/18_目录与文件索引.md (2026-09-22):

# 18 目录与文件索引

本文档说明正式工程中每个目录的用途，并约定文档引用使用相对于当前文件的路径。

## 根目录

- `README.md`：项目方向、范围、当前主线和文档入口。
- `CA100.pdf`：用户提供的参考产品说明书。
- `Chessnut_app_user_manual_v1.0.pdf`：用户提供的参考 APP 手册。
- `chess.3mf`：用户提供的 3D 打印国际象棋模型；尺寸核验见 [`mechanical/pieces/3mf模型核验_2026-09-18.md`](../mechanical/pieces/3mf模型核验_2026-09-18.md)。
- `.gitignore`：忽略本地预览图、Python 缓存等生成文件。

## `docs/`

项目决策、系统设计、路线和参考分析。包括目标范围、年度路线图、分工、系统接口、身份识别实验、嘉立创 EDA、固件、前端/AI、自动移子、预算、参考说明书分析、无视觉身份方案、触点回退路线、无触点自行移动路线、屏幕和微信小程序后置方案、项目经理执行建议，以及本轮 3×3 识别定位 BOM 评审。详细新路线见 [`19_无触点身份与自行移动路线评估.md`](19_无触点身份与自行移动路线评估.md)、[`20_屏幕与微信小程序后置方案.md`](20_屏幕与微信小程序后置方案.md)、[`21_项目经理执行建议_2026-09-18.md`](21_项目经理执行建议_2026-09-18.md)、[`22_3x3识别定位试验BOM评审_2026-09-20.md`](22_3x3识别定位试验BOM评审_2026-09-20.md)、[`23_3x3器件连接关系与开发板判定_2026-09-22.md`](23_3x3器件连接关系与开发板判定_2026-09-22.md)、[`24_霍尔与PN5180定位方案取舍_2026-09-22.md`](24_霍尔与PN5180定位方案取舍_2026-09-22.md) 和 [`25_工程重整与一次性采购决策_2026-09-22.md`](25_工程重整与一次性采购决策_2026-09-22.md)。本文档位于 `docs/`，引用根目录文件使用 `../`，引用固件使用 `../firmware/`。

## `hardware/`

硬件采购、引脚、电路和制造资料。

- `hardware/bom/`：采购清单和 BOM；当前第一批主清单见 [`../hardware/bom/3x3首批一次采购清单_2026-09-22.md`](../hardware/bom/3x3首批一次采购清单_2026-09-22.md)，型号和检索入口见 [`../hardware/bom/3x3识别定位采购链接_2026-09-20.md`](../hardware/bom/3x3识别定位采购链接_2026-09-20.md)；原始输入副本见 [`../references/incoming/3x3_PN5180开发板九线圈采购清单_原始_2026-09-22.xlsx`](../references/incoming/3x3_PN5180开发板九线圈采购清单_原始_2026-09-22.xlsx)，旧版本位于 [`../archive/obsolete_2026-09-22/`](../archive/obsolete_2026-09-22/)。
- `hardware/bom/3x3识别定位采购链接_2026-09-20.md`：3×3 候选路线的官方资料、采购检索入口、数量顺序和到货验收条件。
- `hardware/pinouts/`：具体开发板引脚、板卡照片和复核结果；主控表见 [`hardware/pinouts/主控引脚表.md`](../hardware/pinouts/主控引脚表.md)。
- `hardware/eda/`：嘉立创 EDA 原理图、PCB 和分区工程，按 `controller_audio/`、`sensing_tile/`、`motion_driver/` 分组。
- `hardware/fabrication/`：打样、Gerber、装配和加工记录。

## `firmware/`

运行在 ESP32-S3 上的 PlatformIO 工程。入口和共享代码在 `firmware/src/`；身份扫描实现见 [`firmware/src/identity_grid.cpp`](../firmware/src/identity_grid.cpp)；板级和运动分区目录目前是预留位置。编译配置见 [`firmware/platformio.ini`](../firmware/platformio.ini)。

## `software/`

手机 APP、棋局控制器、规则/AI 适配和通信协议。

- `software/android/`：Android 页面、BLE、TTS、本地记录。
- `software/controller/`：硬件无关的状态协调和棋子快照模型。
- `software/engine_adapter/`：Stockfish/UCI 适配设计。
- `software/protocol/`：BLE/串口共用的字段、测试向量和快照格式。
- `software/protocol/piece_identity_record.md`：DS2431 EEPROM 的预写字段和校验格式。

## `tools/`

- `tools/identity_writer/`：独立的 DS2431G/GA 芯片登记、EEPROM 写入和读回校验工具；当前只有边界说明，真实写入驱动待接触座和样品实测后实现。目录说明见 [`tools/identity_writer/README.md`](../tools/identity_writer/README.md)。

## `teacher_report/`

面向指导老师的阶段汇报视图，包含当前状态、项目方向、采购核验、两人分工、月度里程碑、从 `2026-09-19` 开始到 `2026-12-31` 的周任务，以及每周二总结模板。目录入口见 [`teacher_report/README.md`](../teacher_report/README.md)，首份总览见 [`teacher_report/00_阶段汇报_2026-09-18.md`](../teacher_report/00_阶段汇报_2026-09-18.md)。

## `visualization/`

保存离线可打开的阶段目标 3D 展示页面。入口为 [`visualization/阶段进度3D展示.html`](../visualization/阶段进度3D展示.html)；页面是目标效果示意，不能替代 `experiments/` 中的实测数据。

## `mechanical/`

棋盘、运动机构和棋子结构资料。`mechanical/pieces/` 保存棋子底部芯片、触点、腔体和尺寸草案；自动移子结构分别放在 `board/` 和 `gantry/`。

## `experiments/`

实物实验方案、原始数据和照片索引。`identity_2x2/` 是首个身份/格位实验；`identity_8x8/`、`magnetic_coupling/`、`movement_clearance/` 是后续阶段目录。

## `tests/`

自动化测试、特殊棋局和阶段验收。`tests/test_controller_models.py` 是当前 Python 模型测试；`chess_positions/` 保存规则局面；`essential_acceptance/` 保存必要验收脚本和结果。

## `work/`

进行中的任务、记录、采购辅助和旧工程副本。

- `work/第一周任务.md`：首周两人任务。
- `work/三个月无视觉验收清单.md`：三个月展示版验收。
- `work/当前状态.md`：阶段状态快照。
- `work/legacy_pc/`、`work/legacy_tools/`：历史五子棋/视觉工程，只读参考，不代表当前方案。
- `work/DS2401_datasheet.pdf`、`work/DS2411_datasheet.pdf`、`work/DS2431_datasheet.pdf`：器件数据手册；身份器件决策见 [`docs/16_触点对自动移子影响与身份器件决策.md`](../docs/16_触点对自动移子影响与身份器件决策.md)。`DS1990A_datasheet.pdf` 是较大金属接触器件的备选资料，`DS2431_datasheet_latest.pdf` 是同一数据手册的下载副本。

## `references/`

用户提供的历史交接文件、原始压缩包、解压副本和演示资料。这里的内容只作参考；当前项目决策以根目录 `README.md` 和 `docs/` 为准。

- `references/incoming/`：本轮收到的原始候选 BOM 和输入附件副本，评审见 [`docs/22_3x3识别定位试验BOM评审_2026-09-20.md`](../docs/22_3x3识别定位试验BOM评审_2026-09-20.md)。

## `releases/`

对外演示包、APK、固件 bin、演示脚本和版本归档。当前尚未形成正式发布包。

## 路径引用规则

每个 Markdown 文件引用另一个文件时，使用相对于当前文件的 Markdown 链接。例如 `docs/` 内引用 `firmware/src/config.h` 写为 [`../firmware/src/config.h`](../firmware/src/config.h)；根目录引用 `docs/` 时，路径示例写作 `docs/18_目录与文件索引.md`。历史参考文件中的路径不改写，因为它们是原始资料副本。

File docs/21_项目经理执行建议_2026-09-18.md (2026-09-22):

# 项目经理执行建议

**时间 tag：`2026-09-18T20:10+08:00`**

## 先冻结可验收的产品

2026 年的产品定义是：玩家手动移动无电池棋子，棋盘识别棋子 UID 和格位，ESP32-S3 提供屏幕和 BLE 快照，手机/电脑完成规则、AI、难度和语音提示。自动移子、让路、多棋子同步、8×8 最终阵列和量产结构不属于今年的交付。

这条边界必须同时写在采购单、固件状态机、教师汇报和演示脚本中。任何新增功能都先说明会挤占哪个既定交付物。

## 按阶段门投入

1. `G0`：冻结接口包络和采购单。棋子尺寸不冻结为 3MF 原尺寸，只冻结格距、底径、标签槽、棋盘厚度和读头间隙等参数。
2. `G1`：单标签和 2×2 样片通过。每格至少 20 次，覆盖中心、偏心、旋转、相邻棋子和空位；记录成功率、串读率和扫描时间。
3. `G2`：静态 2×2 稳定，争取 4×4。只有有数据才决定扩展阵列，不提前采购 64 格器件或整盘 PCB。
4. `G3`：ESP32、屏幕、BLE、规则、AI 和语音组成可重复演示的闭环；运动机构只记录接口需求。
5. `G4`：教师演示和下一年度决策。把实测通过项、失败项、预算消耗和下一步风险分开汇报。

## 两人协作方式

每人每周约 6 小时，每周只承诺一个主交付物。硬件负责人每周留下接线图、照片、原始数据或固件日志；软件负责人每周留下可运行版本、测试用例或协议样例。每周二冻结本周结果，未达到退出条件就保留问题，不用口头进度替代数据。

每人设置一个主任务和一个可交接的备用任务。连续两周没有可复现实物数据时，立即缩小范围：先保住 2×2 和软件闭环，再决定是否继续 4×4。

## 采购和风险纪律

采购按工程边界分两类：第一批一次买齐完整 3×3 九线圈识别验证系统，并同时买 3–4 个霍尔和磁铁做占位对照；安装和验证仍按单线圈→三线圈→九线圈推进。M3（2026-10-31）通过后再决定 8×8 全盘材料。电机、导轨、电磁铁、64 格 RFID 和整盘量产 PCB 今年不买。

关键风险不是“能否读到一个 UID”，而是“UID 能否在正确格位被唯一归属”。NTAG213 UID 只解决身份，格位必须来自校准的读头坐标、每格天线或占位传感器。若相邻格串读率不为零，先改标签尺寸、线圈和棋盘厚度，不把一次成功展示当成通过。

## 棋子和模型管理

把 `chess.3mf` 当作基线样品，而不是最终尺寸。兵、马、车各打印少量，一枚保留原模型，一枚使用可拆底盖。每次改型建立版本号、测量表、照片和验收结论；确认标签槽和棋盘厚度后再考虑更多棋子。

## 演示完成定义

演示必须能重复完成“读取快照 → AI 给出走法 → 屏幕/语音提示 → 玩家手动移动 → 读取 UID+格位 → 合法性确认 → 进入下一回合”，并能演示放错棋子、放错格和读数不稳定时的可理解提示。不能用模拟动画或单次读数宣称 8×8 已完成。

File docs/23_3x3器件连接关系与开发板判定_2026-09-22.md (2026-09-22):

# 23｜3×3 器件连接关系与开发板判定

**时间 tag：`2026-09-22T21:00+08:00`**  
**对应器件表：** [`../references/incoming/3x3_PN5180开发板九线圈采购清单_原始_2026-09-22.xlsx`](../references/incoming/3x3_PN5180开发板九线圈采购清单_原始_2026-09-22.xlsx)  
**对应 BOM 评审：** [`22_3x3识别定位试验BOM评审_2026-09-20.md`](22_3x3识别定位试验BOM评审_2026-09-20.md)

## 先回答四个关键问题

### ESP32-S3 开发板可以吗？

可以。`ESP32-S3-DevKitC-1-N8R8` 足够作为 3×3 样机主控：它负责 SPI 控制 PN5180、串行输出 9 路线圈选择、读取调试状态、驱动 ST7789 屏幕、保存扫描快照和通过 BLE/USB 输出数据。PN5180 读卡、继电器切换和线圈匹配仍由外部器件完成；ESP32 不直接产生 13.56 MHz 射频，也不直接“看见”标签 UID。

到货后仍要核对具体板卡的模组丝印、USB 数据下载、3.3 V 电源和可用 GPIO。项目中此前为 PN532/触点方案保留的 GPIO 表不能原样套用到本方案，新的 PN5180、595、165、屏幕必须建立一张独立实物引脚表。

### 谁负责定位？

在当前九线圈方案中，**格位由被选中的线圈编号确定**。例如 ESP32 选择 `L_A2`，PN5180 只通过 A2 线圈读卡，则 UID 被归属到 A2。第一批同时购买 3–4 个霍尔和磁铁做占位对照，剩余格位的霍尔接口用 74HC165 预留；霍尔不是身份识别器件。

建议第一版先采用“线圈扫描定位”：一次只使能一个线圈，扫描 9 个通道，记录哪个通道读到哪个 UID。后续如果需要识别“空格、抬起、读不到标签”和防止读场串格，再加入 9 个 DRV5032 + 棋子底部磁铁作为占位层。霍尔不能识别棋子身份。

### 谁负责识别 ID？

**PN5180 + ISO15693 标签**负责识别。PN5180 是射频前端，标签是棋子底部的无源器件；标签被 13.56 MHz 磁场供电并返回唯一 UID。棋子不需要电池，也不需要自己的微控制器。

标签建议粘在棋子底部的可拆圆盘或底盖内侧，标签与磁铁之间预留非金属间隔；先用一枚标签做读距和磁体干扰实验，再批量粘贴。

### 多个线圈怎样传输信息？

不是九个线圈同时把数据传给 ESP32。正确流程是：

```text
ESP32-S3
  │ SPI：命令、UID数据
  ▼
PN5180（一个读卡器）
  │ 射频端口
  ▼
RF-SW-9CH：9路高频 DPDT 继电器
  │ 只接通一路
  ├── L_A1 ── 标签/棋子 A1
  ├── L_A2 ── 标签/棋子 A2
  ├── L_A3 ── 标签/棋子 A3
  ├── L_B1 ── 标签/棋子 B1
  ├── L_B2 ── 标签/棋子 B2
  ├── L_B3 ── 标签/棋子 B3
  ├── L_C1 ── 标签/棋子 C1
  ├── L_C2 ── 标签/棋子 C2
  └── L_C3 ── 标签/棋子 C3

ESP32 GPIO/SPI ──> SN74HC595 ──> ULN2803 ──> 9个继电器线圈
ESP32 GPIO/SPI <── SN74HC165 <──（可选）9个霍尔输出
ESP32 SPI ──> ST7789 屏幕
ESP32 USB/BLE ──> 电脑网页/Android/后续小程序
```

PN5180 读到的是当前被选中线圈里的标签 UID；“A2”来自继电器选择编号，不是标签自己报告的坐标。

## “必须有九路切换板”这句话是否正确

这句话需要改成更准确的版本：

> 市售 PN5180 开发板可以解决“一个读卡器如何读一个线圈”的问题，但不能自动完成“一个读头如何选择九个棋格线圈”。如果坚持一个 PN5180 轮询九格，就必须增加九路射频切换网络；它可以是 9 个高频 DPDT 继电器，也可以是经过射频验证的 RF 开关芯片/开关板。普通 ESP32 开发板不会自动提供这部分功能。

所以“九路切换板不可避免”只对**单 PN5180、九个独立线圈、逐格扫描**这个架构成立。并不是所有定位方案都必须这样：另一种路线是九个独立读头，或一个移动读头，但它们成本、布线和机械复杂度更高。当前 3×3 验证采用一个 PN5180 + 九路线圈，九路 RF 切换是核心部件。

## 采购表的缺项和风险

| 项目 | 现状 | 影响 | 处理 |
|---|---|---|---|
| 占位检测 | 第一批含 3–4 个 DRV5032 和磁铁 | 其余格位暂时没有独立占位输入 | 先做 3–4 格对照；接口预留到 9 路，M3 后按数据决定是否补齐 |
| 线圈参数 | ANT-24-V1 尚未有实测电感/Q/谐振数据 | 24 mm 外形接近 25.5 mm 格距，邻格串读风险高 | 到货后逐个测量；不要在未实测前批量焊接 9 个 |
| RF 继电器 | 9 个直接采购成本和寄生风险较高 | 射频损耗、触点寄生和控制错误可能同时出现 | 先只装 1 个继电器+1 个线圈；再扩 3 个，最后 9 个 |
| 电源 | 5 V 4 A + 3.3 V 模块 | 原理可行，但 PN5180/屏幕/继电器必须共地，注意反灌 | 先用现有可调电源限流调试；固定电源到货后再接入 |
| 屏幕 | ST7789，和旧 ILI9341 方案不同 | 驱动库、分辨率和 GPIO 定义不能混用 | 以到货实物为准，优先写“状态监视器”而非完整棋盘 UI |
| 线圈接口 | U.FL 连接器数量不足/未确认 | 长杜邦线会改变射频匹配 | 线圈到 RF 切换板使用短同轴或固定阻抗连接；先核对接口类型 |
| 继电器驱动 | ULN2803 输入高电平余量需实测 | 3.3 V 逻辑可能需要确认吸合电流 | 先用单路测线圈电流和吸合可靠性，再扩展 |

## 本周末到货后的顺序

1. 给所有板卡、屏幕、继电器和标签拍照，记录丝印、版本和实际接口。
2. 只接 ESP32-S3 + ST7789，烧录屏幕监视器：显示扫描通道、UID、错误码、重试次数和串口连接状态。
3. 只接 ESP32-S3 + PN5180 成品模块 + 一枚 ISO15693 标签，先确认 SPI 通信和 UID 连续读取。
4. 单独测试一个 `G6K-2F-RF-V` 继电器和一只线圈，验证“未选通道无读卡、选通通道可读卡”。
5. 复制到 3 个线圈并接入 3–4 路霍尔，再完成九路线圈安装；未完成单线圈匹配前，不把九路 RF 板通电接到 PN5180。

## 监视器软件选择

本周采用双层监视器：

- **屏幕监视器：** ST7789 显示当前通道、读取 UID、重试次数、状态（`EMPTY`/`READ_OK`/`READ_FAIL`/`UNSTABLE`）和继电器编号，适合现场脱离电脑观察。
- **电脑串口网页：** ESP32 通过 USB 输出结构化 JSON 行，电脑浏览器页面读取串口并显示九格表格、原始 UID、扫描耗时和错误日志。网页作为详细调试工具，不依赖 Android 或微信小程序。

这样可以先验证硬件信号，再接手机软件；两种显示使用同一份快照字段，避免重复设计。

## 采购表复核补充（2026-09-22）

- 当前表可以支撑 3×3 原理验证，但“定位”不是由标签完成：PN5180 读出标签 UID，线圈编号提供棋格坐标。
- ESP32-S3 不能直接驱动九个射频线圈；它只输出选择控制信号。RF-SW-9CH-V1 或九个合适的高频 DPDT 继电器负责切换射频通路。
- SN74HC595 负责扩展选择位，ULN2803 负责继电器线圈的电流驱动；二者不是射频器件，不能代替 RF 切换网络。
- SLIX2 Wet 标签是无源身份器件，粘在棋子底部；它不记录棋盘位置，也不需要电池。
- 采购前必须核对 PN5180 板是否允许外接天线、RF-SW-9CH 是否同时切换 RF 两端、G6K 完整型号是否为 RF 版本，以及 ANT-24-V1 在实际格距下的邻格串读。
- 第一批已纳入 3–4 个霍尔传感器和磁铁；它们先做部分格位的占位对照，其余 5–6 路接口用 74HC165 预留，M3 后再决定是否补齐。

## 推荐连接关系

ESP32-S3 SPI/控制线 → PN5180；PN5180 RF 端 → RF-SW-9CH-V1 → 当前选中的 ANT-24-V1 线圈 → 棋子底部 SLIX2 标签。ESP32-S3 → SN74HC595 → ULN2803 → RF 继电器控制线。ESP32-S3 SPI → ST7789 屏幕；USB 串口 → 电脑网页监视器。

## 当前结论

“普通开发板不能自动完成一个读头切换九个线圈”这句话的工程含义基本正确，但“九路切换板不可避免”不是物理上的绝对命题。只要采用一个 PN5180 加九个独立线圈逐格扫描，就必须有九路射频切换网络；改成九个独立读头或移动读头才可取消它。

## 霍尔传感器与 NFC 定位方案取舍（2026-09-22）

在每个棋格下方放一个霍尔开关、在棋子底部放一枚小磁铁，霍尔只能输出“该格有棋子/无棋子”，不能识别是哪一个棋子；身份仍由 PN5180 和 ISO15693 标签完成。

| 方案 | 身份 | 占位 | 建议 |
|---|---|---|---|
| 仅 PN5180 逐格扫描 | 能 | 读到 UID 即视为有 | 当前主线 |
| 霍尔 + PN5180 | 能 | 有/无更快 | 稳定性阶段可选 |
| 仅霍尔 | 不能 | 能 | 不满足国际象棋识别 |

第一批直接购买 3–4 个霍尔和磁铁做“线圈编号 + UID”与“有/无占位”的对照；不一次安装 9 个霍尔，避免首轮调试变量过多。74HC165 已按 9 路扩展预留，M3 后根据占位对照结果决定是否补齐其余霍尔。霍尔和磁铁不需要棋子供电，不会直接限制未来自动移子，但磁铁会与未来电磁铁或铁质机构耦合，届时需重测。

核查报告中关于 PN5180 外接天线、九路射频切换和串读的判断应视为工程假设。PN5180 天线匹配、电容电阻值、RF-SW-9CH-V1 的双线切换和 ANT-24-V1 的邻格串读，都必须用实物原理图、NanoVNA 和实际标签测试确认。

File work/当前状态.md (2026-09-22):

# 当前状态

更新时间：2026-09-22 21:00

## 已完成

- 已建立正式工程根目录 `F:\projects\wanxiang-chess`。
- 已冻结项目范围：个人使用国际象棋、两人小组、今年不做自动移子、Android 优先。
- 已确定第一阶段直接做 3×3 九线圈识别验证，不再把第一批采购拆成单线圈/三线圈/九线圈三次。
- 已建立 ESP32-S3、PN5180、RF-SW-9CH、ANT-24-V1、74HC595/165、ULN2803、ST7789、霍尔和磁铁的连接关系。
- 已建立 10～12 月 Excel 计划，M3 日期为 2026-10-31。
- 已将旧计划和旧采购版本移入 `archive/obsolete_2026-09-22/`。

## 当前采购边界

第一批一次采购完整 3×3 九线圈验证系统：9 个线圈、RF 切换网络、主控、PN5180、标签、显示、继电器控制、两片 74HC165、3～4 个霍尔、磁铁、匹配件、连接件和非金属面板。8×8 全盘材料等 M3 通过后再决定。

## 当前仍待验证

- PN5180 开发板是否支持目标外接线圈和匹配网络。
- RF-SW-9CH-V1 是否已装继电器，是否同时切换 RF 两条线路。
- ANT-24-V1 的谐振、Q 值和相邻格串读。
- DRV5032 的实际感应距离、磁铁方向和对标签读距的影响。
- ESP32-S3 到货后的实际 GPIO、供电和 USB 配置。

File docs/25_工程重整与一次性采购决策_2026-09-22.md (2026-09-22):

# 工程重整与一次性采购决策

时间 tag：2026-09-22

## 当前冻结主线

第一阶段采用一个 PN5180、九个棋格线圈、一个九路 RF 切换网络、棋子底部无源 ISO15693 标签和 ESP32-S3 主控。PN5180 读取 UID，线圈编号提供坐标；ESP32 负责调度、显示、日志和通信。

霍尔传感器不是身份器件，只做有/无棋子的占位层。由于两个 74HC165 可以串联读取 16 路输入，9 个霍尔在接口上完全可接入；两个 74HC595 可以串联输出 16 路，9 个继电器控制也有余量。

## 方案可行性

| 子系统 | 结论 | 当前风险 | 验证方式 |
|---|---|---|---|
| ESP32-S3 主控 | 可行 | 实际引脚和供电需复核 | 到货拍照、万用表、最小固件 |
| PN5180 + ISO15693 | 可行 | 模块是否支持外接天线、SPI 接口 | 单标签连续读取 |
| 九路线圈逐格扫描 | 原理可行 | 邻格串读、线圈匹配 | NanoVNA + 逐格扫描 |
| RF-SW-9CH | 条件可行 | 是否双线 DPDT、触点寄生 | 原理图和通断测试 |
| 霍尔 + 磁铁 | 可行 | 感应距离、磁场与 RF/未来机构耦合 | 先做 3 路对照 |
| ST7789 | 可行 | 实物引脚和驱动型号 | 单独显示测试 |

## 本次一次性采购建议

### 必须一次买齐

- ESP32-S3-DevKitC-1-N8R8 ×1，建议备用 ×1。
- PN5180 外接天线/匹配开发板 ×1；如预算允许备用线圈接口件。
- ANT-24-V1 线圈 ×9，建议多买 1–2 只备用。
- RF-SW-9CH-V1 ×1。
- G6K-2F-RF-V DC5 ×9；如果 RF-SW-9CH 已自带继电器，不要重复购买 9 只，先向卖家确认。建议备用 1–2 只。
- SN74HC595 ×2，建议备用 ×1。
- ULN2803A/ULN2803D ×2，建议备用 ×1；若实测驱动余量不足，再换 TPL7407LA/MOSFET。
- ISO15693 SLIX2 标签 12–15 枚。
- ST7789 2 寸屏 ×1，建议备用 ×1。
- 5 V 4 A 电源 ×1；3.3 V 稳压模块 ×1，建议备用 ×1。
- U.FL/同轴转接件按 RF-SW-9CH 接口数量购买，至少留 2 个备用。
- NanoVNA-H4 ×1。
- DRV5032 霍尔开关 ×3，棋子底部 D6×2 或相近尺寸磁铁 ×6；用于本轮对照和备用。
- 74HC165 ×2，建议备用 ×1；原采购表缺少它们，但霍尔阵列需要。
- 3.3 V/5 V 去耦电容、排针、端子、短同轴线、面包板或洞洞板、保险丝。

### 本次不要买

- 自动移子电机、导轨、完整机械手。
- 64 格完整线圈。
- 九个独立 PN5180 读头。
- 大批量棋子标签和大批量霍尔。
- 量产 PCB。

## 为什么建议本次就买霍尔和 74HC165

两次采购间隔约半个月，而霍尔器件价格低、体积小、接口已经预留。一次买 3 路样品不会显著增加预算，却能在 10 月识别测试中直接比较“PN5180 单独扫描”和“霍尔 + PN5180”。不建议此时直接买满 9 路霍尔，因为它们会增加安装和调试工作；但 74HC165 按两片购买，后续扩展到 9 路时无需改主控接口。

## 采购前的两个确认动作

1. 向 RF-SW-9CH-V1 卖家索要原理图，确认是否已经包含 9 个 G6K-2F-RF-V；如果包含，采购表中的 9 个继电器删除，避免重复。
2. 向 PN5180 模块卖家确认外接天线接口、天线匹配网络和 SPI 电平；没有这些资料时，只买 1 块用于验证，不批量增加。

## 分阶段验收

- E0：ESP32 + ST7789 显示通道和状态。
- E1：PN5180 + 单线圈 + 单标签稳定读 UID。
- E2：1 个 RF 继电器切换 1 个线圈。
- E3：3 个线圈逐格读 UID。
- E4：3 个霍尔输出与 3 个线圈结果一致。
- E5：九路线圈静态快照。

任何一个阶段失败，先停在该阶段定位问题，不同时增加新的变量。

相关文件：

- 引脚规划：`../hardware/pinouts/主控引脚表.md`
- 连接示意：`../hardware/wiring/3x3_PN5180_九线圈连接示意.md`
- 霍尔取舍：`24_霍尔与PN5180定位方案取舍_2026-09-22.md`
- 10–12 月计划：`../teacher_report/plans_2026-10_12/万象实体互动桌_10-12月计划与3x3执行表_2026-09-22.xlsx`

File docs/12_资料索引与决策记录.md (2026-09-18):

# 12 资料索引与决策记录

## 历史资料

- 原交接文件：[`../references/original_handoff/万象实体互动桌_项目完整交接文件.md`](../references/original_handoff/万象实体互动桌_项目完整交接文件.md)
- 原始压缩包：[`../references/original_archive/万象实体互动桌_全包工程.zip`](../references/original_archive/万象实体互动桌_全包工程.zip)
- 解压参考：[`../references/extracted/万象实体互动桌_全包工程/`](../references/extracted/万象实体互动桌_全包工程/)

历史工程以五子棋、摄像头 ArUco、网页演示和单 XY 自动移动为主。它的代码骨架、协议问题和测试记录可用于参考，但不代表国际象棋新方向已经完成。

## 已核实的公开参考

- [Espressif ESP32-S3 官方产品页](https://www.espressif.com.cn/en/products/socs/esp32-s3)：BLE、Wi-Fi、SPI/I2C/UART 等能力；具体开发板引脚仍需按手中实物核对。
- [NXP PN5180 官方产品页](https://www.nxp.com/products/PN5180)：可作为 NFC 识别前端候选，不能据此证明 8×8 定位方案可行。
- [PN5180 天线设计指南 AN11740](https://www.nxp.com/docs/en/application-note/AN11740.pdf)。
- [PN5180 NanoVNA 天线设计 AN12810](https://www.nxp.com/docs/en/application-note/AN12810.pdf)。
- [Stockfish UCI Protocol and Commands](https://official-stockfish.github.io/docs/stockfish-wiki/UCI-Protocol-and-Stockfish-Commands.html)：可调技能、思考时间和 UCI 参数。
- [Stockfish Developers](https://official-stockfish.github.io/docs/stockfish-wiki/Developers.html)：UCI 集成方向及 GPLv3 注意事项。

## 决策记录

| 日期 | 决策 | 原因 |
|---|---|---|
| 2026-09-09 | 首发国际象棋 | 用户明确选择，规则和 AI 目标稳定 |
| 2026-09-09 | Android 优先 | 用户明确选择，降低首发平台范围 |
| 2026-09-09 | 两人各 6 小时/周 | 用于排期，合计约 12 人时/周 |
| 2026-09-09 | 首版手机本地 AI 优先 | 控制成本，避免过早确定棋盘算力 |
| 2026-09-09 | 自动移动后置 | 识别和语音闭环先证明价值 |
| 2026-09-09 | 多子先顺序让路 | 用户场景首先是实体路径受阻，非已确认同步需求 |

## 已更新决策（2026-09-18）

- 主线不采用摄像头识别；优先验证平滑棋盘、被动 NTAG213/磁编码身份和静态格位识别。DS2431G/GA 触点仅作静止棋子电气基线，自动移子顺延。
- 主控优先 ESP32-S3-DevKitC-1-N8R8 或同等 ESP32-S3 开发板，首批两块。
- 被动标签 UID、颜色/角色、磁编码盘类型和对局状态分开保存；DS2431 仍按独立 EEPROM 记录管理。
- 棋盘表面保持平滑；自动移动优先采用下方磁力耦合，不默认采用夹爪或凸起触点。
- 棋盘后置加入 2.8 inch ILI9341 SPI 屏幕；微信小程序保留为前端候选，先固定 BLE/串口协议。

## 未决问题

- 最终棋盘外形尺寸、厚度和棋子底座尺寸。
- 2×2 无触点读距、相邻格串读率、格位归属和扫描周期。
- V1 前端选 Android 调试端还是微信小程序；当前先不绑定具体前端。
- 语音语言、扬声器位置和音量目标。
- 单磁头移动是否能满足个人使用体验。

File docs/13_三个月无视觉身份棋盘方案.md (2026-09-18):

# 13 三个月无视觉身份棋盘方案

## 方案状态（2026-09-18 更新）

原“无摄像头、人工移子、DS2431 触点识别”方案降为电气基线。当前优先验证“无摄像头、平滑棋盘、被动身份标签、静态读头/位置层扫描”的路线。DS2431G/GA + 触点只在无触点路线读距或抗干扰失败时回退；自动移子不在本阶段。

产品闭环如下：

```text
被动 NFC UID/磁编码棋子
        ↓ 光滑非金属棋盘面
棋盘下方读头/位置层样片
        ↓ 按坐标扫描 UID
ESP32-S3 生成棋盘快照
        ↓ BLE
Android 棋局、规则、Stockfish、语音
        ↓
玩家按语音移动棋子，设备验证源格、目标格和棋子 UID
```

每个格位的直接结果是 `EMPTY` 或一个 UID。被动标签的 UID 作为物理身份，颜色、角色和对局当前状态由前端注册表维护。这条路线具有自己的硬件特征，不依赖摄像头或图像模型。

## 为什么不用 PN532 作为主方案

PN532/NTAG213 适合做单个标签的登记实验，但一个读头只能回答“附近读到了哪个 UID”，不能回答它位于 8×8 的哪一个格。若要每格安装读头或天线，天线互扰、布线、切换和调谐会把三个月目标变成射频阵列项目。因此 PN532 不列入首批主链路；如果需要做非接触标签对比，只买 1 套实验件。

## 无触点身份方案的实验边界

开发板和芯片选型核验见 [`docs/14_开发板与器件选型核验.md`](14_开发板与器件选型核验.md)，自动移子影响见 [`docs/16_触点对自动移子影响与身份器件决策.md`](16_触点对自动移子影响与身份器件决策.md)。

- 棋子身份候选：13–16 mm、13.56 MHz、ISO14443A 的 `NTAG213` 小标签；必须实测通过 3 mm 非金属板后的读距。
- 移动候选：棋子底部放 6×2 mm NdFeB 圆片，棋盘下方用磁力滑台驱动；驱动磁场关闭后再读 UID。
- 位置读取：首轮只做 2×2 读头/线圈样片，验证四格隔离，不购买 64 格 RFID 阵列。
- 回退方案：`DS2431G/GA` + 触点和 `74HC4067` 作为静止棋子电气基线。

## 关键风险

1. 标签在 3 mm 棋盘下读距不足或相邻格串读。应先缩小线圈、改变标签尺寸/位置和扫描时序，不能直接购买 64 格阵列。
2. 磁力驱动件靠近 NFC 线圈或磁传感器，可能造成失谐、饱和或误判。驱动停止后再读取，并记录磁体与读头距离。
3. 滑台坐标误差导致“读到 UID 但格位不准”。必须记录停位误差和目标格容差，必要时增加机械标定或低摩擦定位结构。
4. 玩家或磁力台架移动棋子时可能出现源格和目标格同时变化。设备应先进入 `UNSTABLE`，待 UID 和坐标稳定后再提交一步。

## 三个月展示闭环

1. 调试端或后续前端连接棋盘并读取初始快照。
2. 用户登记棋子：读取被动标签 UID，选择颜色和角色。
3. AI 返回一条合法走法，例如 `Ng1-f3`。
4. 语音/屏幕提示玩家手动移动。
5. 读头/位置层确认目标格 UID，前端将棋局推进。
6. 玩家完成一步后，系统检查合法性并交给 AI 思考下一步。
7. 放错棋子、放错格、读距不足或串读时，前端提示具体原因，不猜测局面。

三个月不承诺自动移子、64 格 RFID 阵列、联网对战或量产结构。

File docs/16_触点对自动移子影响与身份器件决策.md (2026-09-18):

# 16 触点对自动移子影响与身份器件决策

> **路线更新（2026-09-18）**：本文保留为触点电气基线和回退方案。当前主路线改为无触点身份/定位与棋盘下方磁力移动，详见 [`19_无触点身份与自行移动路线评估.md`](19_无触点身份与自行移动路线评估.md)。

## 结论先行

棋盘触点不会从原理上限制后期自动移子，但会把机械方案限制在“移动完成后必须稳定落到触点上”。如果未来采用棋盘下方磁铁拖着棋子在表面滑动，触点凸起会带来卡滞、磨损和漏读，属于明显限制；如果采用抬起—平移—放下的磁吸或夹具结构，触点只是最后的到位复核，限制较小。自动移子器件不能只把棋子推到格子边缘就算完成，必须满足以下闭环：

```text
磁吸/夹持搬运 → 目标格定位 → 棋子落下 → 触点接触 → UID 读回 → 到位确认
```

因此触点方案与自动移子是可以共存的，甚至有利于自动移子后的到位复核。真正的限制是：

- 棋子底部必须有一个可重复接触的平面或环形区域；
- 机械磁头/夹具不能撞坏触点，也不能让棋子停在触点之间；
- 移动路径要有轻微的最后定位动作，不能只依靠 XY 坐标误差；
- 棋子被抬起时触点会断开，软件要把这段时间视为 `UNSTABLE`，不能立即判定为吃子或走子；
- 触点暴露在表面会磨损、氧化和积尘，最终结构需要可更换触点或可清洁面。

触点不会限制磁吸自动移子，但会限制“棋子悬空移动、任意角度放置、极薄底座”和“完全无定位的平面滑动”。这些都是可接受的工程约束。

## 推荐身份器件：DS2431G/DS2431GA

`DS2431` 更符合“每个棋子是一个已经写入信息的小器件”的要求。它同时具有：

- 工厂写入的 64-bit ROM 唯一序列号；
- 1 kbit 1-Wire EEPROM，可预写棋子编号、颜色、初始角色和校验字段；
- 通过 IO 和 GND 两个接触面工作，不需要电池；
- `DS2431G` 约 6 × 6 × 0.9 mm，`DS2431GA` 约 3.5 × 6.5 × 0.75 mm；
- 数据手册明确说明 SFN 封装适用于电气机械接触应用，但不适合直接焊接。

因此，首选采购应是可确认真品和封装的 `DS2431G+U` 或 `DS2431GA+U`。它不是“焊到棋子里的小 PCB”，而是一个可以装入棋子底部浅腔、由棋盘弹簧触点压接的芯片。

参考：[`work/DS2431_datasheet.pdf`](../work/DS2431_datasheet.pdf)。

这满足“每个棋子是一个写入信息的小器件，而不是一块需要电池的电路板”。但仍要区分两件事：

1. DS2431 的 ROM UID 是工厂唯一身份，不能修改；
2. EEPROM 可以预写初始信息，但升变、替换和对局中的当前角色仍由手机里的 UID 注册表和棋局状态保存。

### 低风险备选：DS2401+

`DS2401+` 只提供 64-bit 工厂 UID，没有用户 EEPROM。它适合首轮验证 ESP32-S3、1-Wire、触点、多路器和扫描协议，不能单独满足“芯片内写入棋子信息”的最终语义。若 DS2431G/GA 采购不到真品，可以先用少量 `DS2401+ TO-92` 进行电气实验，软件用 UID 注册表绑定角色。

因此芯片不需要也不应该存储“白马”这类不可变角色。升变和备用棋子都可以由软件处理。

## 芯片放置方式

首版不建议把裸芯片直接塞进狭小棋腔后再依赖手工接线。建议做成可更换的底部身份件：

1. 在棋子底部开一个约 7–10 mm 的浅腔，具体尺寸以实物底座和 DS2431G/GA 样品测量为准；
2. 将 DS2431G/GA 平放在腔体内，芯片底部 IO/GND 接触面朝下；
3. 芯片周边用绝缘定位框固定，不能让芯片本体承担棋子重量；
4. 棋盘格用两个有弹性的镀金弹簧针或柔性触点接触 IO/GND，接触点略高于格面；
5. 用浅定位圈让棋子落下后自动居中，触点不依赖棋子朝向；
6. 芯片从棋子底面略微内凹，避免自动移动时被刮擦。

建议先改造 1 枚兵、1 枚马和 1 枚车，量出底座直径、腔体深度、触点间距和触点压力，再决定是否给整套棋子加工。

## 尺寸与识别精度

芯片本体足够小，真正影响识别精度的不是存储容量，而是机械接触和 1-Wire 信号质量：

- 棋子底部触点的有效接触面积；
- 棋子相对格中心的偏心量；
- 触点弹力和表面氧化；
- 触点到 74HC4067 的线长和寄生电容；
- 上拉电阻和扫描重试；
- 棋子抬起/落下时的去抖窗口。

首版不要用“读到一次 UID”作为成功标准。每个格位应连续读取若干次，在同一个 UID 连续稳定后才提交；出现 CRC 错误、多个格同时变化或 UID 在相邻格跳变时进入 `UNSTABLE`。

推荐初始验收指标：

- 静态单格 100 次读取成功率 ≥ 98%；
- 旋转 0°/90°/180°/270° 均通过；
- 偏心 1–2 mm 仍能识别，超过范围明确提示重新放置；
- 两个相邻格不会互换 UID；
- 抬起后 2 秒内识别到稳定新局面；
- 断线重连后通过完整快照恢复，不重复提交动作。

## DS2431 的写入流程

DS2431 的 EEPROM 只在装入棋子前写一次或少量写入。写入夹具需要：

1. ESP32-S3 或 USB 1-Wire 主机；
2. 可靠的 DS2431G/GA 接触座；
3. 写入时的强上拉/供电能力。数据手册给出的 EEPROM 编程电流约为 0.8 mA，写入期间总线不能被其他任务打断；
4. 写后读回 EEPROM，并同时校验 ROM CRC 和应用层校验字段；字段布局见 [`software/protocol/piece_identity_record.md`](../software/protocol/piece_identity_record.md)。

棋盘正常扫描只需读 ROM 和必要的 EEPROM 字段，不需要棋子带电池。三个月目标可以先只读 UID，随后补写入工具；不要在棋盘 64 格扫描总线上直接尝试写入。

## DS2431 EEPROM 写入工具任务

首轮不把写入功能塞进 64 格扫描固件，而是单独制作“登记/写入夹具”。这样可以在桌面上逐枚写入、读回和标记芯片，避免扫描总线上的多路器、长线和其他棋子影响编程时序。

### 最小硬件

- 1 块 ESP32-S3-DevKitC-1-N8R8，或一台已验证的 USB 1-Wire 主机；
- 1 个 DS2431G/GA 专用接触座，保证 IO、GND 和定位可靠；
- 4.7 kΩ 1-Wire 上拉；
- 可控的 3.3 V 供电和写入期间的强上拉开关；
- 记录标签、芯片袋和一张 UID 登记表。

### 工具功能顺序

1. `READ_ROM`：读取 64-bit ROM UID，并校验 ROM CRC。
2. `READ_EEPROM`：读取前 16 字节，解析 [`software/protocol/piece_identity_record.md`](../software/protocol/piece_identity_record.md) 中的字段。
3. `WRITE_EEPROM`：只允许在接触座中写入一枚芯片；写入前显示 UID 和目标字段，写后必须整页读回。
4. `VERIFY`：校验 magic、版本、side、initial_role、piece_number、batch_id 和 CRC16。
5. `EXPORT`：导出 UID、写入时间、字段、读回结果和失败原因，作为实验记录。

### 通过条件

- 同一芯片连续写入/读回 3 次均一致；
- 断电后重新读取仍能得到相同字段；
- 写入失败时工具明确报告失败，不把芯片标记为可装配；
- 扫描固件与写入工具使用同一 UID 字节顺序和 CRC 约定。

写入工具的代码、日志和导出文件放在 `tools/identity_writer/`；在工具完成前，允许只使用 `READ_ROM` 做 2×2 电气实验。

## 是否需要额外的霍尔传感器

不是身份识别必需件。霍尔传感器只能告诉系统“这里有磁体/棋子可能在位”，不能告诉“这是哪一枚棋子”。它可以作为抬起/落下的快速触发或去抖辅助，但不应替代 DS2431/DS2401 身份芯片。首版可以先不买，等触点实验显示抬起事件难以稳定分辨时再加入少量 DRV5033。

## 触点与自动移子的接口要求

机械设计要给每格留下：

- 棋子最终落位的定位特征；
- 磁头或夹具接近时不碰触点的高度余量；
- 棋子从格中心被吸起时不会刮擦触点的间隙；
- 触点更换和清洁的维修入口。

自动移子第一阶段仍只做单棋子台架。运动控制完成后，必须由 `ID_SCAN` 读回目标格 UID 才返回 `MOTION_DONE`；如果读不到，进入 `PAUSED`，而不是把逻辑局面直接推进。

## 备选身份器件

- `DS2411A`：也是唯一 ID，但没有用户 EEPROM；只有 DS2431 采购受阻时才作为低风险 UID 备选。
- `DS2401+`：无用户 EEPROM，适合电气原型，不作为最终“芯片内保存角色”的首选。
- NFC/RFID 标签：无需电池，但逐格定位需要每格天线/读头，不能用一个 PN532 直接解决 64 格位置问题。

当前回退决策：如果无触点身份路线在读距、串读或磁干扰测试中失败，再采购少量 `DS2431G/GA` 样品和接触座，验证静止棋子电气识别；同时可买 3–5 枚 `DS2401+ TO-92` 做低风险 1-Wire 电气备份。不要一次采购 32 枚最终芯片。

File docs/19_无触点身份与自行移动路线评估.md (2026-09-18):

# 无触点身份与棋子自行移动路线评估

> 本文讨论的是项目后续创新方向。2026 年只执行静态身份/格位识别与软件闭环，自动移子不作为今年验收项。

**时间 tag：`2026-09-18T18:30+08:00`**  
**决策编号：`D-2026-09-18-MOVE-01`**

## 结论

如果项目的核心创新是棋子在棋盘上自行移动，棋盘表面不应默认采用凸起弹簧针或镀金触点。原触点方案保留为低风险电气基线和故障对照，不再作为自行移动产品的主感知架构。

推荐主路线改为：

```text
棋子底部：被动身份标签 + 磁力耦合件
        ↓ 无接触读取
光滑、非金属棋盘面
        ↓
棋盘下方 XY 磁力驱动/扫描滑台（后续研究）
        ↓
磁力搬运棋子，扫描位置并复核身份
```

这里的“自行移动”指棋子不被机械夹爪抓取，棋盘下方的磁场或磁性滑台驱动棋子在表面移动。棋子仍然可以不带电池；运动能量由棋盘下方机构提供。

## 触点方案原本有什么价值

触点不是没有用，它解决的是三个工程问题：

1. 通过棋盘给无电池芯片供电；
2. 用 1-Wire 直接读取每枚棋子的唯一 UID；
3. 棋子落位后可以用电气读回确认“确实在这一格”。

所以触点很适合“静止棋子、玩家手动移子、低成本验证”的第一版电气原型。但它不等于完整的自行移动方案。

## 为什么触点会限制自行移动

- 凸起触点会增加滑动阻力，磁力不足时棋子可能卡在触点边缘；
- 棋子经过触点时会磨损、刮擦或改变接触压力；
- 触点要求棋子最后垂直落位，磁力平移不能只靠 XY 坐标完成；
- 触点区域要在棋子底部预留两个导电面，会限制底部磁体、标签和底座结构；
- 触点氧化、灰尘和轻微偏心会造成漏读，运动状态下更难判定是机械问题还是识别问题；
- 若改成抬起后搬运再放下，核心机构就变成夹具/磁吸搬运，而不是棋子在平面上自行移动。

## 新主路线的身份与定位分层

### A 方案：被动 NFC/13.56 MHz 标签 + 下方移动读头

棋子底部放置一个小尺寸 `NTAG213` 或同类 ISO14443A 被动标签；棋盘下方的 XY 滑台同时携带磁力驱动件和 NFC 读头线圈。滑台扫描某个格中心时读取标签 UID，格位由滑台坐标确定，身份由 UID 确定。

优点：棋子无需电池；棋盘表面可以完全平滑；标签 UID 可直接作为棋子身份；与后续磁力移动的结构方向一致。

风险：13.56 MHz 线圈尺寸、棋盘厚度、磁体和金属件会影响读距；一个固定读头不能同时知道 64 格所有棋子，因此需要下方读头扫描或每格天线阵列。首轮只做 2×2，不购买 64 格 RFID 阵列。

### B 方案：被动磁编码 + 磁传感器阵列

棋子底部放置多个小磁体或磁性编码片，棋盘每格用磁传感器读取磁场签名。它更贴合磁力驱动，但驱动磁场可能使传感器饱和，必须在“驱动磁场关闭后”再识别；32 枚棋子需要足够多的可区分编码，不能只放一个磁铁。

首轮只做单枚、三种编码的磁场实验，不直接承诺 64 格量产。`DRV5033` 只能检测有无磁体，不能单独识别棋子身份。

### C 方案：1-Wire 触点作为备选

`DS2431G/GA + 触点` 保留在独立实验夹具和低成本人工版中。如果无触点路线在棋盘厚度、读距或磁干扰上失败，仍可用它快速完成“识别和软件闭环”，但不把它表述成最终自行移动结构。

## 3D 打印验证顺序

1. 先按 [`../chess.3mf`](../chess.3mf) 原尺寸打印兵、马、车各 1–2 枚，测量底座直径、底面平整度、内部空间和棋盘格间隙。
2. 在同一底座上做三种可拆身份盘：空白盘、`NTAG213` 标签盘、磁编码盘；不要一开始打印 32 枚。
3. 用一枚 `6 mm × 2 mm` 的 `NdFeB N35/N42` 圆片做磁力耦合候选，先测试吸附力和 NFC 读距，再决定是否扩大直径或增加厚度。
4. 用一块约 3 mm 厚的非金属平板做 2×2 位置样片，逐格测试读头是否串读相邻格。
5. 只有身份读取、相邻格隔离和静态定位都通过后，才冻结棋盘模型；磁力移动另立后续阶段。

## 年底前的新阶段门

- `M0`：打印样品尺寸确认，标签/磁体能放入底部且不影响落位；
- `M1`：单枚标签在 2–3 mm 非金属板下可重复读取；
- `M2`：2×2 位置读取能区分四个格，不出现相邻格串读；
- `M3`（后续）：棋盘下方磁力驱动能移动一枚棋子，停下后读头能复核 UID；
- 未通过 `M1/M2` 时，不采购 64 格读头、整盘 PCB 或运动机构；回退到触点电气基线或重新调整标签/线圈。

## 对采购的直接影响

暂缓批量购买 `DS2431`、`74HC4067`、40 个弹簧针和 4×4 触点底板。优先采购少量 3D 打印耗材、13.56 MHz 被动标签、小型 NFC 读头/线圈和磁力耦合样件。ESP32-S3 仍保留，既可连接 NFC 读头，也可驱动后续磁力机构。

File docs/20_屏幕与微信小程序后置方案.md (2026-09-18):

# 棋盘屏幕与微信小程序后置方案

**时间 tag：`2026-09-18T18:35+08:00`**

## 棋盘屏幕可行性

可以实现。ESP32-S3 有足够的 SPI、GPIO 和内存驱动一个小型 TFT 屏幕，屏幕可以显示：

- 当前回合、玩家颜色和难度；
- AI 给出的走法和语音提示文字；
- 设备连接、扫描进度、读取错误和暂停状态；
- 后续自动移动的执行状态和故障提示。

首轮建议使用 `2.8 inch ILI9341 SPI 240×320` 模块，要求卖家明确 3.3 V 逻辑兼容。暂不购买带复杂触摸层的屏幕，先验证显示、供电和与传感/运动接口的引脚隔离。若需要更大界面，再评估 `3.5 inch ILI9488 480×320`；它的刷新和显存要求更高，不作为首批器件。

屏幕不应占用身份读头、运动限位和调试串口的专用引脚。实际 GPIO 分配要等 ESP32-S3 开发板实物到手后填写 [`../hardware/pinouts/主控引脚表.md`](../hardware/pinouts/主控引脚表.md)。

## 微信小程序可行性和边界

微信小程序可以作为后期交互层候选，微信提供 BLE 扫描、连接、服务发现和特征读写接口。它能减少单独维护 Android 页面带来的界面适配工作，但不能完全消除平台差异：蓝牙权限、系统后台限制、机型兼容性、调试工具和小程序审核约束仍需要实测。

因此当前不把 Android 或微信小程序写死为硬件接口。先固定 BLE/串口消息协议和棋局数据模型，使用 PC/Android 模拟器完成规则、AI 和识别流程；后期再把同一协议接入微信小程序。

## 后置实施顺序

1. 先完成无触点身份/定位实验和 ESP32 快照协议；
2. 再用 2.8 inch ILI9341 做棋盘状态屏；
3. 设备闭环稳定后，验证微信 BLE API 的连接、断线恢复和数据吞吐；
4. 最后决定微信小程序是否作为正式交互端，Android 是否保留为调试工具。

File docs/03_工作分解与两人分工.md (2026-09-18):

# 03 工作分解与两人分工

估算为初步工程量，不是承诺工期。难度 1 表示常规，5 表示高风险且需要实物迭代。

| 编号 | 工作包 | 人时 | 难度 | 负责人 | 交付物 |
|---|---|---:|---:|---|---|
| W01 | 范围、尺寸、接口冻结 | 20 | 2 | 共同 | 规格与决策记录 |
| W02 | 棋子底座、DS2431/DS2401 和触点样片 | 35 | 4 | A | 结构样片和材料表 |
| W03 | 2×2/4×4 身份位置识别 | 70 | 5 | A | 1-Wire 扫描程序、实验数据 |
| W04 | 全盘识别方案与标定 | 75 | 5 | A | 8×8 方案和误读处理 |
| W05 | 国际象棋规则与状态机 | 55 | 4 | B | 规则库、FEN/PGN 测试 |
| W06 | BLE 协议与设备传输 | 35 | 3 | A+B | 协议实现和日志 |
| W07 | Android 棋盘、设置、记录 | 60 | 3 | B | APK/源码和断线恢复 |
| W08 | AI 适配与难度标定 | 30 | 3 | B | 引擎适配、难度表 |
| W09 | 语音输出与提示状态机 | 20 | 2 | B | 音频资源和提示规则 |
| W10 | 主控/电源/音频 EDA | 40 | 4 | A | 原理图、PCB、BOM |
| W11 | 单 XY 运动台架 | 70 | 5 | A | 运动程序、标定和安全记录 |
| W12 | 让路、停车、动作复核 | 55 | 5 | A+B | 顺序动作规划器 |
| W13 | 总控与状态协调 | 45 | 4 | B | 统一控制程序 |
| W14 | 整机测试和资料整理 | 40 | 3 | 共同 | 验收记录、问题清单 |

## 分工原则

### A：硬件与底层

棋子结构、DS2431/DS2401 触点、识别实验、ESP32 固件、供电、音频接口、嘉立创 EDA、运动控制和机械安全。A 的接口输出必须包含测量数据和失败状态，不能只返回“成功/失败”。

### B：软件与对局

国际象棋规则、Android、BLE 数据模型、Stockfish 适配、语音、日志和测试工具。B 的逻辑动作不能直接驱动电机，必须经过状态协调层和设备确认。

### 共同工作

每周同步协议和数据模型；在 G1、G2、G3 阶段门做共同验收。零碎时间用于加速，不进入基础交付承诺。

## 工作条目统一格式

每个任务只保留：编号、目标、负责人、依赖、预计人时、难度、交付物、通过条件、当前状态、证据路径、下一步。

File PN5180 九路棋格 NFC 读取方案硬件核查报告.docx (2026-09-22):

PN5180 九路棋格 NFC 读取方案硬件核查报告

核查日期：2026-09-22　｜　核查对象：PN5180 开发板、RF-SW-9CH-V1 九路射频切换板、G6K-2F-RF-V 高频继电器、ANT-24-V1 天线线圈、ULN2803A 驱动电路　｜　核查性质：基于官方数据手册与公开资料的桌面设计核查，不替代样机实测。

总体结论：五项核查中，PN5180 外接线圈支持；G6K-2F-RF-V 是正式完整的 RF 型号（订货须追加线圈电压后缀）；射频切换必须同时通断 TX1/TX2 两条差分线，这是设计硬前提，需对照 RF-SW-9CH-V1 原理图核实；ANT-24-V1 在标准棋格下可通过设计避免邻格串读，但必须限功率并逐格实测；ULN2803A 在 3.3V 逻辑下驱动继电器不属于可靠设计，建议 pin 兼容替换为 TPL7407LA 或改用逻辑电平 MOSFET。

RF-SW-9CH-V1、ANT-24-V1 未检索到公开资料，按项目自定义板名处理；相关结论为条件性结论，闭环条件是提交两块板的原理图、实际棋格尺寸与标签型号。

# 1. 核查范围、对象与方法

本次核查围绕“单颗 PN5180 经九路射频切换分时驱动九枚棋格线圈”的硬件方案，回答五个指定问题，并给出依据、风险与整改动作。核查依据为 NXP、OMRON、TI/ST 的官方产品页、数据手册与应用笔记，以及关键参数的定量核算；未进行样机测试。

核查对象 | 核查内容 | 主要依据
PN5180 开发板 | 是否支持外接线圈及接入条件 | NXP OM25180FDK 套件清单、AN11740 天线设计指南
RF-SW-9CH-V1 | 是否同时切换射频两条线路（项目自定义板，无公开资料） | PN5180 差分驱动拓扑、G6K-2F-RF-V 接点结构
G6K-2F-RF-V | 型号是否完整、关键参数是否适用 | OMRON K290-CN1 规格书、产品页
ANT-24-V1 | 实际棋格尺寸下是否邻格串读（按外径约 24mm 线圈推断） | 磁场几何衰减估算、ISO/IEC 14443 标签启动场量级
ULN2803A | 3.3V 控制输入能否可靠驱动继电器 | TI ULN2803A 数据手册、G6K DC5 线圈参数、链路裕量核算

# 2. 结论汇总

序号 | 核查项 | 结论 | 风险等级 | 处置动作
1 | PN5180 外接线圈 | 支持，外接线圈是标准用法 | 低 | 按 AN11740 重新调谐匹配；市售模块需断开板载线圈，禁止并联
2 | 九路射频切换 | TX1/TX2 两条差分线必须同时通断；每路一枚 DPDT 继电器即满足，待原理图核实 | 高（前提性） | 核对每路线圈两腿均经继电器两组接点，未选线圈两端全浮空
3 | G6K-2F-RF-V 型号 | 型号成立，订货号须追加 DC3/4.5/5/12 之一 | 低 | BOM 写全，如“G6K-2F-RF-V DC5”；注意线圈极性
4 | ANT-24-V1 邻格串读 | 标准 50–55mm 棋格可避免；小号棋格高风险，须实测 | 中（条件性） | DPC 限功率、闲置线圈浮空、逐格邻位扫描标定、软件多次确认
5 | ULN2803A 3.3V 驱动 | 室温能吸合但无手册保证、最坏链路低于吸合门限，不可靠 | 高 | 替换 TPL7407LA 或逻辑电平 MOSFET；加输入下拉与续流回路

# 3. 逐项核查依据

## 3.1 PN5180 开发板支持外接线圈

结论：支持。PN5180 芯片本身不含天线，外接线圈本就是其标准用法：TX1/TX2 为差分天线驱动输出，经 EMC 低通滤波与谐振匹配网络连接线圈，RX 从容性分压回路取接收信号；天线设计指南给出 TX1/TX2 之间目标阻抗约 20Ω。

- 官方 OM25180FDK 开发套件即按“可换外接天线”配置：PNEV5180B 主板带 65mm×65mm 天线，另含一块带匹配器件的 30mm×50mm 天线板，以及约 30mm×50mm 的空白天线匹配 PCB 三块，专门用于实施定制天线匹配；NXP 另提供 OM29263ADK 天线开发套件与天线设计工具。
- 更换线圈后必须重新设计谐振电容与匹配，使谐振频率为 13.56MHz 并满足目标阻抗与 Q 值，不能只把线圈接上就用。
- 市售廉价 PN5180 模块通常没有外接连接器，板载线圈经匹配电路硬连；改外接时应在板载线圈焊盘或 0Ω 跳线处改线并断开原线圈，严禁外接线圈与板载线圈直接并联，否则电感并联导致失谐。

## 3.2 RF-SW-9CH-V1 必须同时切换两条射频线路

结论：TX1/TX2 是一对差分驱动腿，九路切换必须把两条腿同时接通、同时断开；只切一条腿的设计不成立。推荐拓扑为星型结构：读卡器侧 EMC 滤波、谐振匹配与 RX 取样九路共用，每路线圈的两条腿各经过一只 DPDT 继电器的一组接点，选中路闭合，其余八路线圈两端完全浮空。

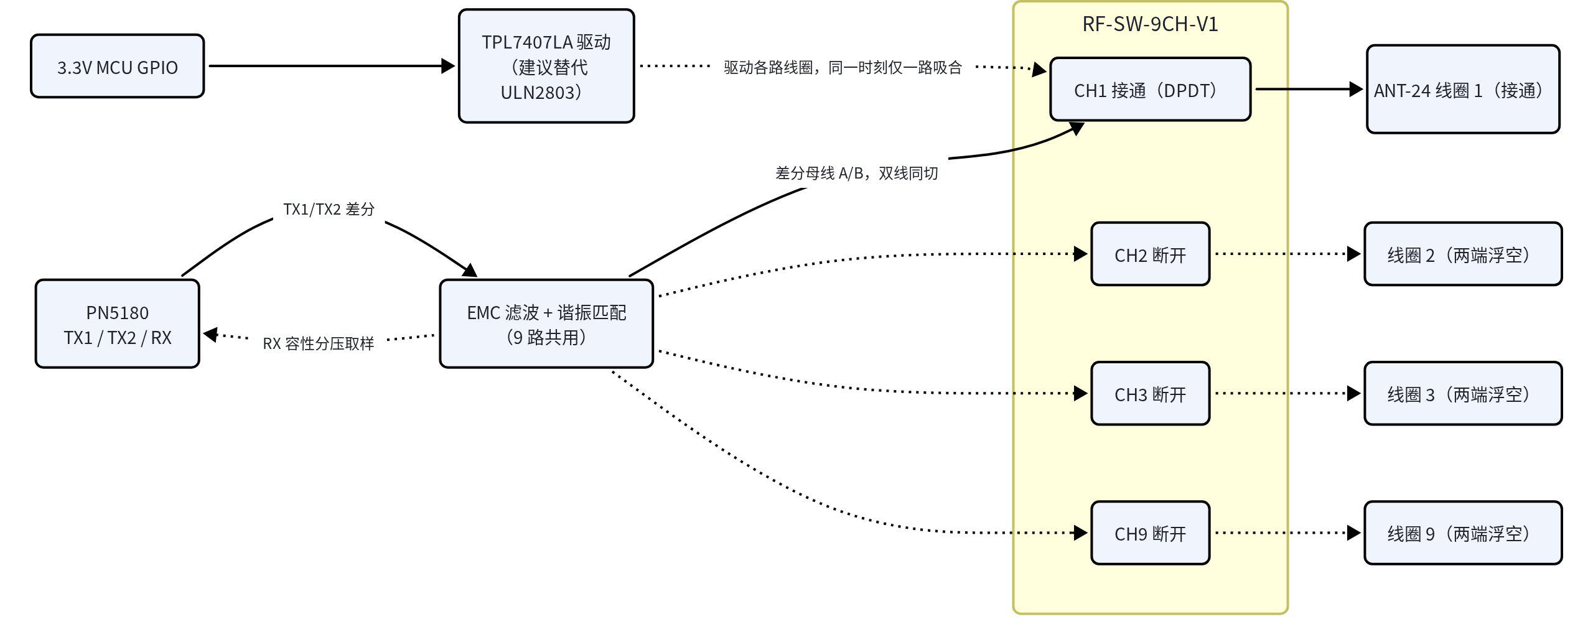
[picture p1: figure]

图中实线为当前接通路径，虚线为断开的开关支路与控制关系；CH1 仅为示意，实际由 MCU 分时选通九路中的一路。

读图要点：

- G6K-2F-RF-V 为 2 极（2 Form C，即 DPDT）继电器，一枚即可同时通断 A/B 两条差分母线，且本身就是为 100Ω 差分对高速切换设计的器件；若 RF-SW-9CH-V1 每路使用一枚该型号且使用常开接点（NO 接通、NC 悬空），则双线同切天然满足。
- 未选线圈两端必须全浮空。若用单极器件只切一条腿，另一条腿公共相连，九个线圈将经公共腿互相并联，造成谐振失谐、Q 值崩塌，并把选中路的场耦合到其他线圈，这是邻格串读最主要的硬件来源。
- RX 建议放在共用匹配侧通过容性分压取样，无需随路切换；九枚线圈的电感量与匹配必须一致，否则换路后谐振点漂移。
- 切换时序应为：PN5180 关射频（RF OFF）→ 继电器动作（动作时间 3ms 以内，约 1.4ms）→ 稳定后再开射频轮询，避免带载热切换并延长接点寿命。

对 RF-SW-9CH-V1 的交付前核对清单：

核对项 | 合格判据
每路线圈两条腿的通路 | 均经过同一枚继电器的两组接点（DPDT），无公共直连线
未选线圈状态 | 万用表测量两端对母线均断开（全浮空），NC 脚悬空未接地或共线
同一时刻吸合路数 | 逻辑互锁，任何时刻最多一路吸合
九路线圈一致性 | 线圈电感、谐振频率与 Q 值一致（建议 VNA 或阻抗扫描留档）

## 3.3 G6K-2F-RF-V 为完整 RF 型号，订货须注明线圈电压

结论：G6K-2F-RF-V 是 OMRON 正式量产的完整高频继电器型号系列，面向高速差分传输信号切换，13.56MHz NFC 频段使用性能远优于其规格上限。但它是型号主体，完整订货号必须追加线圈额定电压后缀。

项目 | 内容
型号结构含义 | 2＝2 极（DPDT/2c）；F＝外 L 型表面安装端子；RF＝高频对应；V＝8GHz 频段、高速差动传输适用规格（差分阻抗 100Ω，单端 50Ω）
可选线圈电压 / 订货示例 | DC3、DC4.5、DC5、DC12；订货示例：G6K-2F-RF-V DC5。1GHz/3GHz 用途的姊妹系列为 G6K(U)-2F(P)-RF(-S,-T)，选型勿混
DC5 线圈参数 | 线圈电阻 237Ω、额定电流 21.1mA、功耗约 100mW；动作电压 ≤80%（即 ≤4.0V，23℃），复位电压 ≥10%
高频与机械指标 | 差分插损 ≤3dB@8GHz、隔离 ≥15dB@8GHz；动作时间 ≤3ms（约 1.4ms）；封装 11.7mm×7.9mm×7.1mm。13.56MHz 下插损与隔离均远优于规格值
使用提示 | 规格书提示注意线圈极性与推荐焊盘；高频特性随基板布局变化，需在实际基板上确认；长期连续通电场景建议磁保持型，本方案为分时扫描，不受此限

## 3.4 ANT-24-V1 邻格串读：标准棋格可避免，小号棋格须实测

结论：邻格串读是否发生，取决于棋格边长、标签位置、发射功率与“未选线圈是否真正断开”四个条件，不是线圈单独决定的。串读判据是邻格标签处磁场达到标签启动场量级（ISO/IEC 14443 约 1.5A/m 量级）。按外径 24mm 线圈、标签距盘面高度 8mm、邻格标签半径按 10mm 且贴共用边（最恶劣位置）做磁偶极量级估算：

棋格边长 s | 线圈边间隙 | 最劣水平距离 ρ | 邻格场隔离（量级估算） | 判读
55mm（标准棋格） | 31mm | 33mm | 约 −71dB | 几何隔离充分，不会串读
45mm | 21mm | 23mm | 约 −63dB | 充分
40mm | 16mm | 18mm | 约 −57dB | 足够，仍建议限功率
35mm（小号盘） | 11mm | 13mm | 约 −51dB（近场，实际更差） | 必须限功率并逐格实测
30mm（迷你盘） | 6mm | 8mm | 约 −43dB（近场模型失效） | 高风险，标签几乎搭边

估算假设：线圈半径 12mm；本格轴上磁场按 r²/(r²+h²)^1.5 衰减，邻格赤道向按 0.5/(ρ²+h²)^1.5 衰减，仅用于比较趋势；ρ 与线圈半径同量级时远场模型失效，真实隔离只会更差，一律以实测为准。

设计与验证措施：

- 用 PN5180 的 DPC 动态功率控制（或降低供电、串联电阻）把每路功率压到“本格最高位标签稳定读取”的最小值，建议留 3–6dB 余量即可；磁场随距离约三次方衰减，降功率对邻格抑制收益极大。
- 硬件上保证未选线圈两端全浮空（见上一节），避免线圈互感绕过几何隔离。
- 逐格标定：标签放在八个邻格的共用边中点与对角点（最劣位），遍历九路开关和棋盘四角位置，达到“本格 100% 读到、邻格 0 误读”；覆盖标签批次与棋子底座高度公差。
- 辅助手段：格间采用接地过孔栅栏或开缝铜箔削弱侧向场；线圈下方贴铁氧体片把场向上引导；软件要求连续多次（如三次中两次）读到同一 UID 才确认落子。

## 3.5 ULN2803A 不建议在 3.3V 逻辑下直接驱动继电器

结论：3.3V GPIO 直连 ULN2803A 驱动 G6K-2F-RF-V DC5，室温下通常能吸合，但该工况不在数据手册保证范围内，最坏链路低于继电器 80% 吸合门限，高温或老化后存在不吸合风险，不建议作为定型设计。

参数 | 数值 | 来源 / 说明
输入串联电阻 / 设计对象 | 2.7kΩ / 5V TTL、CMOS | TI 数据手册，非 3.3V 工况设计
保证导通输入电压 V_I(on) 最大值 | 2.4V @ Ic=200mA | 3.3V 高于门限，逻辑可导通；21mA 轻载时实际门限更低
3.3V 时输入电流（估算） | 约 0.72mA | 按 (3.3−1.35V)/2.7kΩ；手册 3.85V 时典型 0.93mA，模型自洽
Vce(sat) 保证值 | ≤1.1V @ Ic=100mA、Ii=250μA | 本工况 Ii≈0.72mA、Ic=21mA，典型压降约 0.5–0.8V（推断，无 3.3V 保证值）
G6K DC5 吸合门限 | ≤4.0V（额定 80%，23℃） | 线圈 237Ω、21.1mA、约 100mW

链路情形 | 线圈实得电压 | 判读
典型（5.0V 供电，Vce 0.5–0.8V） | 约 4.2–4.5V | 高于 4.0V 门限，室温可吸合，裕量仅 0.2–0.5V
最坏（供电 −5% 为 4.75V，Vce 1.1V） | 约 3.65V | 低于 4.0V 吸合门限；高温使线圈电阻增大，风险叠加

整改方案对比：

方案 | 要点 | 评价
TPL7407LA 直接替换 | 与 ULN2803A 引脚兼容，输入明确支持 3.3V 逻辑，MOS 输出在 21mA 下压降约 0.1V 量级，线圈得电约 4.9V | 推荐，改动最小、裕量充足
逻辑电平 N-MOSFET | 如 AO3400A 类（Vgs(th)≤1.5V、低 Rds(on)），栅极加 10kΩ 下拉，外加续流二极管 | 推荐用于新板布局
保留 ULN2803A 改造 | GPIO 开漏 + 输入上拉至 5V（须确认 GPIO 5V 容忍或串肖特基隔离），回到手册工况；或改用 DC12 线圈与 12V 电源 | 可接受，增加约束

无论采用何种驱动：MCU 上电期间 GPIO 为高阻，输入端必须加下拉电阻防止继电器误吸；ULN2803A 的 COM 脚接 +5V 以使用内部续流二极管（MOSFET 方案需外加）；固件保证同一时刻仅一路吸合。

# 4. 整改与验证清单

序号 | 动作 | 验收标准 | 状态
1 | 核对 RF-SW-9CH-V1 原理图与通断：每路线圈两腿均经 G6K-2F-RF-V 两组接点，NC 悬空 | 九路逐一验证：选中路两腿导通，其余路线圈两端对母线全断开；任意时刻最多一路吸合 | 待办
2 | BOM 与订货号补全线圈电压后缀 | BOM、采购单与实物印字一致（如 G6K-2F-RF-V DC5） | 待办
3 | 继电器驱动改为 TPL7407LA 或逻辑电平 MOSFET，加输入下拉与续流 | 供电 4.75V、整机高温条件下九路均可靠吸合与释放 | 待办
4 | 九枚 ANT-24 线圈与匹配一致性调谐 | 谐振 13.56MHz，各路电感、阻抗与 Q 值一致并留档 | 待办
5 | DPC 限功率标定与邻格扫描 | 本格最高位标签 100% 读取；八邻格最劣位 0 误读；覆盖全板位置与标签批次 | 待办
6 | 切换时序验证（RF OFF→换路→RF ON） | 示波器/逻辑分析仪确认无带载热切换，轮询稳定 | 待办
7 | 外接线圈接入方式确认（PN5180 板型） | 官方套件走天线匹配板；市售模块断开板载线圈并重调匹配，无并联 | 待办

# 5. 待确认事项与前提假设

- RF-SW-9CH-V1 为项目自定义板名（无公开资料）：结论以“每路一枚 G6K-2F-RF-V、DPDT 星型切换”为推断前提，须提交原理图与位号表闭环。
- ANT-24-V1 按外径约 24mm 线圈推断；实际外径、匝数、电感量、谐振电容与 Q 值待提供。
- 棋格实际边长、盘面材料与厚度、棋子底座高度、标签型号与尺寸（如 NTAG21x 系列及标签直径）待提供；小号棋格（≤35mm）的串读结论必须以实测为准。
- PN5180 板的具体型号（官方 PNEV5180B/OM25180FDK 或市售模块）待确认，决定外接线圈的物理接入方式。
- 本报告中的磁场隔离为量级估算，驱动裕量中的典型 Vce(sat) 为数据手册参数推算，均不构成数据手册保证值；最终以样机测试记录为准。

# 6. 参考资料

1. NXP：OM25180FDK 面向 POS 读卡器的 PN5180 NFC 开发套件产品页 (https://www.nxp.com.cn/design/design-center/development-boards-and-designs/OM25180FDK)（含 PNEV5180B、30mm×50mm 天线板与三块定制匹配 PCB 清单）。
2. NXP：AN11740《PN5180 Antenna design and tuning》 (https://www.nxp.com.cn/docs/en/application-note/AN11740.pdf)（TX1/TX2 差分拓扑、RX 容性分压、目标阻抗约 20Ω）。
3. OMRON：K290-CN1《G6K-2F-RF-V 表面安装高频继电器》规格书 (https://components.omron.com.cn/datasheet_pdf/K290-CN1.pdf)（型号结构、DC3/4.5/5/12、237Ω/21.1mA、≤80% 吸合、8GHz 差动指标）。
4. OMRON：G6K-2F-RF-V 产品页 (https://components.omron.com/sg-en/products/relays/G6K-2F-RF-V)（8GHz Band Miniature DPDT High Frequency Relay）。
5. Texas Instruments：ULN2803A 数据手册 (https://people.ece.cornell.edu/land/courses/ece4760/FinalProjects/s2008/dmh64_hs284/dmh64_hs284/datasheets/ULN2803A.pdf)（2.7kΩ 输入、V_I(on)≤2.4V@200mA、Vce(sat) 保证表、Ii=0.93mA@3.85V）。
6. STMicroelectronics：ULN2803A 产品页 (https://www.st.com.cn/zh/interfaces-and-transceivers/uln2803a.html)（2.7kΩ 输入电阻对应 5V TTL/CMOS 的定位说明）。

|（注：部分内容可能由 AI 生成）

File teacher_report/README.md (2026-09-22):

# 教师汇报与计划

当前计划工作簿：[`plans_2026-10_12/万象实体互动桌_10-12月计划与3x3执行表_2026-09-22.xlsx`](plans_2026-10_12/万象实体互动桌_10-12月计划与3x3执行表_2026-09-22.xlsx)。

第一批一次采购完整 3×3 九线圈验证系统，验证按单线圈→三线圈→九线圈推进；霍尔先买 3～4 个做位置层对照，M3 截止 2026-10-31。原始旧版工作簿仍保留为历史快照，避免覆盖时丢失。

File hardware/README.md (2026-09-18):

# 硬件资料

保存采购清单、开发板引脚、电路、打样和装配资料。主控/器件选型见 [`../docs/14_开发板与器件选型核验.md`](../docs/14_开发板与器件选型核验.md)。

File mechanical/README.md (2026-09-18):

# 机械资料

保存棋盘、棋子和自动移子结构资料。触点与棋子身份结构见 [`pieces/规格草案.md`](pieces/规格草案.md)；运动研究见 [`../docs/09_自动移子与避障研究.md`](../docs/09_自动移子与避障研究.md)。

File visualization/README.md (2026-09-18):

# 阶段 3D 可视化

本目录保存不依赖构建工具的阶段演示页面，用于向老师和组员直观看到每个阶段要达到的目标效果。

- `阶段进度3D展示.html`：离线打开即可使用的 CSS 3D 原型；点击阶段按钮或播放按钮切换场景。
- 页面中的棋子、读头、位置层、后续运动接口和屏幕是示意模型，不代表已经完成的实物；真实尺寸、读距和扫描误差以 `F:/projects/wanxiang-chess/experiments/` 下的实测记录为准。

相关技术决策见 [`../docs/19_无触点身份与自行移动路线评估.md`](../docs/19_无触点身份与自行移动路线评估.md) 和 [`../docs/20_屏幕与微信小程序后置方案.md`](../docs/20_屏幕与微信小程序后置方案.md)。

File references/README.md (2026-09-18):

# 参考资料

保存用户提供的交接文件、原始 ZIP、解压副本和历史演示。内容只作参考，当前决策以根目录 [`../README.md`](../README.md) 和 [`../docs/`](../docs/) 为准。

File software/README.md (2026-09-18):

# 软件

保存 Android、硬件无关控制器、规则/AI 适配和通信协议。软件分层见 [`../docs/17_开发板选择与系统分层.md`](../docs/17_开发板选择与系统分层.md)。

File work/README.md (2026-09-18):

# 工作区

保存当前周任务、状态快照、三个月验收、器件数据手册和历史工程副本。历史代码位于 [`legacy_pc/`](legacy_pc/) 与 [`legacy_tools/`](legacy_tools/)，只作参考。

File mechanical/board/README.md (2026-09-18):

# 棋盘结构

预留平滑非金属棋盘面、格位几何定位、下方读头/磁力滑台间隙和底部维护结构图纸。当前不把凸起触点作为棋盘表面默认结构；触点仅在电气基线样片中使用。3MF 尺寸与打印建议见 [`../pieces/3mf模型核验_2026-09-18.md`](../pieces/3mf模型核验_2026-09-18.md)。

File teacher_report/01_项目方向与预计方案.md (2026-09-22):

> **当前执行修订（2026-09-22）**：第一阶段直接做 3×3 九线圈识别验证。第一批一次购买完整 3×3 所需器件，霍尔先买 3～4 个做占位对照；10 月按单线圈、三线圈、九线圈逐步装调，M3 前完成九线圈静态验证。

# 项目方向与预计方案

**时间 tag：`2026-09-18T18:50+08:00`**
**适用周期：`2026-09-19` 至 `2026-12-31`**

## 方向冻结

项目做个人使用的国际象棋实体互动桌，核心方向是棋子在平滑棋盘上可被识别，自动移动作为后续创新方向。先解决“棋子是谁、棋子在哪一格”，主链路不使用摄像头视觉识别。

## 分层方案

| 层 | 首版方案 | 年底要证明的内容 |
|---|---|---|
| 棋子 | 3D 打印可拆底盖；被动 NTAG213 标签或磁编码盘 | 单枚 UID 可读；标签、磁体和底座不互相干扰 |
| 棋盘感知 | 平滑非金属面；小型读头/位置层；DS2431 触点为回退基线 | 2×2 能区分四格，争取 4×4；记录扫描周期和串读 |
| 主控 | ESP32-S3 | 固件可烧录、扫描、去抖、生成快照、BLE 传输 |
| 前端 | Android 调试端；微信小程序后置候选 | 固定协议，后续选择合适交互端 |
| AI | 手机本地 Stockfish/UCI 或同类引擎 | 至少 3 档难度，能返回合法走法 |
| 自动移动 | 只预留下方磁力耦合、状态字段和机械接口 | 2026 年不做实物；下一年度再评估单棋子台架 |

## 用户流程

1. APP 读取或载入棋局快照。
2. AI 计算下一步并输出颜色、棋子、源格和目标格。
3. 手机语音或棋盘屏幕提示走法。
4. 玩家手动放置，读头或位置层确认 UID 和格位。
5. APP 校验合法性和 UID 一致性；错误时提示重新放置，不猜测局面。
6. 玩家完成自己的回合，APP 再请求 AI。

## 关键判定

- 若标签读距不足或出现相邻格串读，先调整线圈、棋盘厚度和读头结构；不直接采购 64 格阵列。
- 若标签在相邻格串读或读距不足，先调整线圈、棋盘厚度和位置层；不直接采购 64 格阵列。
- 只有 2×2 无触点数据稳定后，才决定是否扩到 4×4 或 8×8；运动板不列入今年采购。
- Android 和微信小程序都先使用固定快照；真实前端在 BLE 协议稳定后再确定。

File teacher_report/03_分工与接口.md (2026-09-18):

# 两人分工与接口

**时间 tag：`2026-09-18T17:45+08:00`**  
**每周投入：每人约 6 小时，合计约 12 人时**

## 角色

| 角色 | 主要责任 | 每周必须交付 |
|---|---|---|
| A：硬件与底层 | 采购核验、棋子底座、标签/读头、ESP32 固件、供电、EDA 和安全记录；触点只做回退实验 | 实测数据、接线图、固件日志或硬件问题清单 |
| B：软件与对局 | 棋局模型、规则、Android、BLE 数据模型、AI、难度、语音、测试和演示脚本 | 可运行代码、测试用例、界面截图或软件问题清单 |
| 共同 | 每周接口同步、阶段门验收、风险判断、老师汇报 | 每周二一页总结和下周计划 |

## 接口约束

- A 输出的是 `EMPTY`、UID、CRC 错误或 `UNSTABLE` 等可解释状态，不能只返回“成功/失败”。
- B 不直接驱动电机；所有动作必须经过状态协调层和设备确认。
- UID、棋子初始角色、当前角色和棋盘格位分开保存。
- BLE 断线重连后先请求完整快照，不重复提交上一事件。
- 每周二冻结本周数据；之后新增数据标明日期和测试条件。

## 共同验收节点

- `G0`（2026-09-22）：采购单、尺寸假设、接口字段和周计划确认。
- `G1`（2026-10-20）：单枚标签与 2×2 无触点定位读取有重复数据。
- `G2`（2026-11-17）：静态 2×2 通过并争取完成 4×4，前端模拟对局可运行。
- `G3`（2026-12-15）：BLE、屏幕、AI、语音和人工落子流程联调。
- `G4`（2026-12-31）：教师演示包、数据、问题清单和下一阶段建议齐全。

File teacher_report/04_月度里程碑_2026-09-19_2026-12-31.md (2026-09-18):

# 月度里程碑与退出条件

**时间 tag：`2026-09-18T17:50+08:00`**

## 2026 年 9 月 19–30 日：启动、采购和接口冻结

目标：让项目从文档进入可采购、可接线、可并行开发状态。

交付物：采购订单和型号截图；ESP32 引脚核验表；NTAG213/PN532 数据手册记录；2×2 接线草图；Android/PC 棋局模型最小运行版本；周总结记录。

退出条件：两人能说明首版边界；采购物资型号和用途有依据；A/B 使用同一 UID、格位、状态和错误字段。

## 2026 年 10 月：3D 打印棋子、无触点身份和 2×2 定位

目标：先证明“棋子能容纳身份件、标签能读、相邻格不串读”，不急于做整盘。

交付物：兵/马/车打印样品；NTAG213 UID 和读距日志；磁体与标签干扰记录；2×2 无触点定位样片；必要时保留 DS2431 触点对照数据。

退出条件：单枚标签重复读取稳定；2×2 能区分四个格；失败能定位到读距、串读或位置层问题。

## 2026 年 11 月：静态定位扩展和软件底座

目标：把静态读头/位置层和软件快照串起来，同时让软件不依赖真实硬件也能演示完整棋局。

交付物：2×2 稳定数据和可选 4×4 样片；BLE 快照协议；棋盘屏幕 SPI 验证；Android/前端无关棋盘视图；UID 登记；规则、FEN/PGN 和 AI 适配；至少 3 档难度定义。

退出条件：静态定位扩展有明确通过/失败结论；Android 可加载固定快照并完成合法走法和 AI 回合；屏幕能显示基本状态。

## 2026 年 12 月：单棋子闭环和教师演示

目标：把识别、BLE、屏幕、AI、语音和玩家手动放置串成可解释的闭环。

交付物：真实或模拟 BLE 连接；屏幕/语音提示；源格/目标格 UID 校验；放错棋子提示；断线完整快照恢复；10 步演示脚本；采购和实验数据包；下一阶段建议。

退出条件：能演示“AI 指定 → 玩家手动放置 → 识别确认 → 进入下一回合”，并如实说明 4×4/8×8、自动移子、多棋子同步和量产尚未完成。

## 年底阶段门

- 若 2×2 无触点静态识别低于 98% 或相邻格串读，暂停扩展，优先修读头、标签尺寸、棋盘厚度和定位。
- 若无触点身份路线失败，使用 DS2431/DS2401 完成 UID 电气验证，并把它标为静止棋子回退路线。
- 若真实 BLE 延迟影响进度，先用串口/固定快照完成 Android 演示，保留 BLE 接口不改字段。

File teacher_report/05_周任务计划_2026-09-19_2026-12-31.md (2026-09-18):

# 周任务计划

**时间 tag：`2026-09-18T19:00+08:00`**
**规则：每周二总结；每人约 6 小时；每周只承诺一个主交付物**

| 周期 | 周二总结 tag | A：硬件与底层 | B：软件与对局 | 本周交付物与通过条件 |
|---|---|---|---|---|
| 09-19–09-22 | `2026-09-22` | 整理采购链接、核对板卡/芯片参数、记录现有工具 | 确认 UID/格位/状态字段，建立固定快照样例 | G0 采购单、接口字段、首周问题清单 |
| 09-23–09-29 | `2026-09-29` | ESP32-S3 到货核验；确认屏幕/读头 GPIO；尝试烧录最小程序 | 建立棋局模型、UID 注册表和测试数据 | 板卡照片/引脚表；模型测试通过 |
| 09-30–10-06 | `2026-10-06` | 读取 3MF 尺寸和打印首件；记录底座、平整度、格距 | 完成 FEN/PGN 基础读写和初始局面 | 打印测量记录；规则数据样例 |
| 10-07–10-13 | `2026-10-13` | 制作兵/马/车可拆底盖，比较空白盘、标签盘、磁体盘 | 定义棋子角色、颜色、升变和错误状态模型 | 3 类结构样片；角色/UID 模型可测试 |
| 10-14–10-20 | `2026-10-20` | 建立 2×2 无触点样片，测标签 UID、3 mm 板下读距和串读 | 建立快照到局面的转换和异常提示 | G1：2×2 读距/定位数据；失败状态可复现 |
| 10-21–10-27 | `2026-10-27` | 测标签与棋盘材料、偏心和相邻格串读；磁体仅做干扰对照 | 完成合法走法校验和玩家回合状态机 | 2×2 数据表；规则测试集 |
| 10-28–11-03 | `2026-11-03` | 设计 4×4 静态定位样片，不采购整盘机构 | 选择前端无关协议和 Android 调试页面 | 4×4 样片草图；页面骨架 |
| 11-04–11-10 | `2026-11-10` | 制作 4×4 样片或位置层对照，记录 UID/格位时序 | 完成 BLE 消息解析模拟器和断线恢复逻辑 | 4×4 初始数据或明确回退方案 |
| 11-11–11-17 | `2026-11-17` | 整理读距、串读、扫描周期和异常状态原始数据 | 接入本地规则引擎和 AI 适配，定义 3 档难度 | G2：静态定位结论；固定快照可下棋 |
| 11-18–11-24 | `2026-11-24` | 固件输出统一快照、版本和错误码 | 完成 Android UID 登记、棋盘视图和对局记录 | 快照协议联调样例；可显示棋盘局面 |
| 11-25–12-01 | `2026-12-01` | 用真实板卡测试 BLE、屏幕和读头状态，记录延迟和断线 | 接入 BLE 页面/协议适配、设备状态和完整快照恢复 | 前端可连接或有串口替代演示 |
| 12-02–12-08 | `2026-12-08` | 完成静态识别异常提示和屏幕状态固件接口 | 完成屏幕/语音“颜色+棋子+源格+目标格”提示 | 语音/屏幕样例；错误状态映射表 |
| 12-09–12-15 | `2026-12-15` | 做连续扫描、读 UID 和断电重启记录 | 完成 AI 指定走法、玩家手动放置、UID 确认流程 | G3：静态闭环初版 |
| 12-16–12-22 | `2026-12-22` | 修复演示中的读距、重连和日志问题；记录自动移子接口需求 | 完成放错棋子/格位提示、10 步演示脚本 | 可重复演示一次完整流程 |
| 12-23–12-29 | `2026-12-29` | 整理接线图、BOM、UID 登记和实验原始数据 | 整理 APK/源码、测试记录、难度说明 | 教师汇报材料初稿和问题清单 |
| 12-30–12-31 | `2026-12-31` | 共同复盘，确认实测边界和下一阶段硬件建议 | 共同完成演示与下一年度路线 | G4：最终阶段报告、演示和下一步决策 |

## 每周二必须汇报的内容

1. 本周实际投入：A/B 各多少小时。
2. 本周交付物：文件路径、照片、日志或测试结果。
3. 通过/未通过的条件和客观数据。
4. 新增风险、采购变化和需要老师判断的问题。
5. 下周一个主目标和一个备用目标。

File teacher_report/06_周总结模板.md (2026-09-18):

# 周总结模板

**时间 tag：`YYYY-MM-DD`**  
**覆盖周期：`YYYY-MM-DD` 至 `YYYY-MM-DD`**

## 本周结论

- 阶段状态：未开始 / 进行中 / 已通过 / 暂停 / 需要决策。
- 一句话结论：

## 实际投入

| 人员 | 计划小时 | 实际小时 | 主要工作 |
|---|---:|---:|---|
| A | 6 |  |  |
| B | 6 |  |  |

## 交付物与证据

- 文件、照片、日志或测试路径：
- 测试条件：
- 关键数据：
- 通过条件：通过 / 未通过 / 部分通过。

## 风险和决策

- 新问题：
- 已采取措施：
- 是否需要老师判断：是 / 否。

## 下周计划

- A 主任务：
- B 主任务：
- 共同验收点：
- 采购或外部依赖：

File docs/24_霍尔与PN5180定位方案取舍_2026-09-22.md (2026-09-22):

# 霍尔传感器与 PN5180 定位方案取舍

当前主线采用 PN5180 逐格扫描；霍尔传感器只作为占位检测增强，不作为身份识别器件。PN5180 读取棋子底部 ISO15693 标签 UID，线圈编号提供棋格坐标，霍尔传感器加磁铁只判断有无棋子。

试验顺序：单线圈单标签；3×3 逐格 UID；记录空读、误读、邻格串读和耗时；需要时加入 3 个 DRV5032 做对照；确认明显改善后才扩展到 9 个。

相关连接说明：`docs/23_3x3器件连接关系与开发板判定_2026-09-22.md`。

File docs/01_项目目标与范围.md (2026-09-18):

# 01 项目目标与范围

## 项目目标

在 12 个月内完成一台 8×8 国际象棋实体互动桌：棋盘能够识别带唯一身份的棋子及其格位，把局面同步到 Android，调用可调难度的国际象棋引擎，使用扬声器指导玩家落子，并在玩家操作后核对实体局面。自动移动作为独立后续能力接入，不得破坏首版语音指导闭环。

当前三个月优先验证无视觉、无触点身份主线：棋子底部优先采用无需电池的 NTAG213 等被动标签，先做 2×2、争取 4×4 的身份与格位联合识别；DS2431G/GA 与触点只作静止电气回退。芯片身份、预写角色和对局中的当前角色分开管理。三个月版本的具体边界见 [`13_三个月无视觉身份棋盘方案.md`](13_三个月无视觉身份棋盘方案.md)。

## 已确认约束

| 项目 | 决策 |
|---|---|
| 首发棋类 | 国际象棋，标准规则 |
| 目标用户 | 先个人使用，稳定后再评估小规模量产 |
| 团队 | 2 人，每人每周约 6 小时，合计约 12 人时 |
| 首批预算 | 2000–3000 元，按实验结果分批追加 |
| APP | Android 优先 |
| AI | 先评估 Android 本地运行；联网只作为后备，不作为首版依赖 |
| 已有工具 | 万用表、焊接工具、可调电源、基础机械工具 |
| 多棋子运动 | 2026 年不做；只记录接口和后续研究问题 |

## 首年必须交付

- 32 枚棋子具有唯一身份，并与棋种、阵营、当前角色分开建模；首轮只用少量样品完成标签和定位验证。
- 识别棋子当前所在的格位；2026 年验收 2×2，争取 4×4，不承诺 64 格最终阵列。
- 完整国际象棋规则：合法走法、将军、将死、和棋、易位、吃过路兵、升变、悔棋和重新摆局。
- BLE 设备连接、状态快照、递增版本、断线重连和 Android 棋盘显示。
- Android 难度设置、对局记录和 AI 走法显示。
- 语音播报建议走法、错误位置和等待确认。
- 玩家完成手动落子后，系统再次识别并确认；不能只因发出提示就提交走法。
- 自动移动不属于 2026 年交付；仅保留机械接口、状态字段和下一年度实验建议。

## 明确不纳入首年硬性范围

- 语音识别、唤醒词、自然语言聊天和棋局长篇讲解。
- 账号、云端记忆、远程联机、支付和商业内容授权。
- 多个棋子真正同时物理搬运。
- 可直接量产的外观、模具和完整认证。
- 其他棋类、教育包和角色互动内容。

## 版本定义

| 版本 | 目标 |
|---|---|
| V0 | 传感器/识别/规则/协议的台架实验，不承诺完整棋盘 |
| V1 | 语音指导版：玩家手动移动，Android 本地 AI，BLE 同步 |
| V1.5 | 后续研究：单 XY 磁头自动移动和顺序让路实验 |
| V2 | 根据实测需求决定双磁头、多执行器、联网或棋盘内置算力 |

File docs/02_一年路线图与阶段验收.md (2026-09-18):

# 02 一年路线图与阶段验收

> **路线说明（2026-09-18）**：下表是从方案验证到个人稳定样机的一年期参考路线。2026 年 9–12 月只执行静态识别、屏幕、BLE、AI 和语音闭环；触点识别降为回退方案，自动移子、让路和运动机构顺延到后续周期。

按两人合计每周 12 人时估算，全年理论投入约 624 人时。排期只承诺约 450–500 人时，其余用于学习、采购等待、返工和联调。

| 月份 | 阶段目标 | 主要交付物 | 退出条件 |
|---|---|---|---|
| 1 | 需求、尺寸、接口冻结 | 规格表、风险表、协议草案、采购单 | 首发边界可复述，棋子/面板结构样片确定 |
| 2 | 被动标签和棋子底座共存 | 2×2 无触点识别实验记录 | 单枚、旋转、偏心和相邻格读数有数据 |
| 3 | 小阵列定位 | 4×4 无触点样片、扫描程序 | 能稳定关联 ID 与格位，异常可重试 |
| 4 | 国际象棋软件底座 | 规则状态机、PGN/FEN 测试集 | 完整规则测试通过，异常局面不崩溃 |
| 5 | BLE 与 Android 原型 | 连接、快照、日志、棋盘视图 | 断线后可用完整快照恢复 |
| 6 | 语音指导闭环 | AI 适配、语音、人工落子确认 | 从开局到结束可完成一局 |
| 7 | 全盘识别工程化 | 8×8 扫描方案、标定数据 | 明确全盘成本、扫描周期和失败率 |
| 8 | 首版板卡 | 嘉立创 EDA 原理图、BOM、PCB、打样 | 限流上电、主控、传感接口可工作 |
| 9 | 自动移子可行性研究 | XY、磁力耦合和限位需求分析 | 形成下一阶段实验方案，不承诺实物 |
| 10 | 让路问题建模 | 临时停车区、路径规划和风险记录 | 明确多棋子运动的机械难点 |
| 11 | 静态系统联调 | 总控、识别、AI、BLE、语音、屏幕 | 代表性局面连续运行并可暂停恢复 |
| 12 | 稳定样机与下一年评估 | 演示、测试报告、成本表、运动研究清单 | 达到静态 V1 范围；自动移动不作为交付项 |

## 阶段门

- G1（第 3 月）：4×4 无触点身份与格位关联通过后，才允许评估 8×8 阵列。
- G2（第 6 月）：语音指导版独立可玩，自动移子仍保持解耦。
- G3（第 9 月）：完成运动可行性研究和接口定义，不制作整机。
- G4（第 11 月）：静态识别、屏幕、BLE、AI 和语音闭环稳定后，才决定下一年度运动实验预算。

## 周节奏

每周固定 30 分钟接口同步；每人保留一个主任务和一个可交接任务。每周必须留下一个可检查结果，例如识别数据、测试报告、协议用例或可运行构建。

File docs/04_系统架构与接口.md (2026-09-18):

# 04 系统架构与接口

## 数据流

```text
棋子标签/位置传感
        ↓
识别层：下方读头/磁传感器读取 UID + 滑台格位 + 置信度 + 时间戳
        ↓
状态协调层：去抖、局面快照、异常恢复
        ↓
国际象棋规则层：合法性、胜负、特殊规则
        ↓
AI 适配层：返回逻辑走法，不操作硬件
        ↓
表达层：Android 显示 + 语音指导
        ↓（V1.5）
运动执行层：临时停车、磁吸、路径、到位复核
```

## 单一可信状态

软件保存三种状态：

1. `logical_position`：已确认的国际象棋局面，使用 FEN/内部模型表示。
2. `sensed_position`：最近一次稳定识别的 UID—格位快照。
3. `physical_task`：正在执行的提示或运动任务，以及命令 ID、阶段和超时。

只有识别稳定、规则合法、执行确认完成后，才能把逻辑局面推进到下一版本。手动打乱棋盘时进入 `UNSTABLE`，不得猜测用户意图继续下棋。

## 首版 BLE/串口协议

首版格位来自棋盘布线表，不来自图像坐标。固件先返回硬件通道和 UID，Android 再映射为 `a1` 到 `h8`；这样替换 4×4 实验板或调整排线不会改动棋局规则层。

开发初期串口优先，BLE 复用同一行协议或同一消息字段。每个消息包含协议版本、设备 ID、棋局 ID、状态版本、命令 ID 和错误码。

设备到主机：

```text
HELLO,VER,1,DEVICE,wx-001
SNAPSHOT,STATE,12,P08:e2,P17:g1,...
EVENT,LIFT,PIECE,P08,FROM,e2,SEQ,91
EVENT,PLACE,PIECE,P08,TO,e4,SEQ,92
OK,CMD,41,RESULT,SNAPSHOT
ERR,CMD,41,CODE,NOT_STABLE
```

主机到设备：

```text
STATUS?,CMD,41
SNAPSHOT?,CMD,42
VOICE,KEY,move_knight_g1_f3,CMD,43
MOTION,FROM,e2,TO,e4,CMD,44
STOP,CMD,45
```

V1 可以只实现 `STATUS?`、`SNAPSHOT?`、事件上传和 BLE 心跳；运动命令在单棋子磁力台架通过后才开放。DS2431 触点仍可使用同一快照字段，不改变上层协议。

## 前端功能边界

- 扫描和连接设备；首期允许串口调试端、Android 或后续微信小程序接入。
- 显示 8×8 逻辑棋盘、棋子角色和同步状态；棋盘本地屏幕显示简化状态。
- 设置难度、语音开关、音量和本地 AI/联网后备策略。
- 显示当前建议走法、错误提示和恢复按钮。
- 保存本地对局记录、FEN/PGN 和故障日志。
- 断线重连后先请求完整快照，再应用增量事件。

## 必须处理的状态

`SETUP`、`WAIT_PLAYER`、`LIFTED`、`UNSTABLE`、`THINKING`、`VOICE_GUIDANCE`、`WAIT_CONFIRM`、`MOTION`、`PAUSED`、`RESYNC`、`GAME_OVER`。

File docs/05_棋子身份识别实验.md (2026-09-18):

# 05 棋子身份识别实验

> 方向更新：三个月版本不采用摄像头识别。主实验是“棋子底部被动标签 + 无触点格位联合识别”；DS2431/触点只保留为静止电气回退。

身份器件封装、触点和后续自动移子约束见 [`docs/16_触点对自动移子影响与身份器件决策.md`](16_触点对自动移子影响与身份器件决策.md)；实验接线见 [`experiments/identity_2x2/实验方案.md`](../experiments/identity_2x2/实验方案.md)。

## 核心判断

棋子 UID 只回答“是哪一枚棋子”，不能单独回答“在哪个格”。必须验证 UID 与 8×8 格位的联合识别。身份标签、磁体、铁片、面板厚度、铜层和相邻天线会互相影响。

## 推荐路线

> **路线更新（2026-09-18）**：本文件的 DS2431/触点实验保留为电气基线。当前首轮改为使用 [`../mechanical/pieces/3mf模型核验_2026-09-18.md`](../mechanical/pieces/3mf模型核验_2026-09-18.md) 中的 3D 打印兵、马、车，测试 NTAG213 被动标签、磁编码盘和 2×2 无触点读距；不要在无触点数据通过前设计 8×8 固定 PCB。

DS2431 的 ROM 提供唯一身份，EEPROM 可保存初始信息；UID、EEPROM 字段、角色和升变状态仍由 Android 本地数据库分开管理。DS2401 只提供 UID。

## 实验分级

### E05-1 单子材料和标签测试

记录标签型号、UID、标签位置、旋转角度、偏心量、底板材料、面板厚度、读时长、漏读和误读；触点形状和弹簧针压力只在回退实验中记录。

### E05-2 2×2/4×4 联合定位

覆盖空位、相邻棋子、偏心、旋转、放置后稳定、多个棋子同时摆放和不同角色底座。输出每格的 ID、空位和置信度；位置必须来自校准的读头坐标、每格传感器或天线，不能把 UID 当作格位。

### E05-3 连续性与故障

连续扫描至少 100 次，统计每格成功率、邻位串读、单次扫描时间、整阵列周期、重试后成功率。任何“读到 UID 但坐标不确定”的结果都算失败。

### E05-4 后续扩展到 8×8

先做一个 4×4 分区，再评估全盘。记录线圈/读头互扰、扫描周期、布线和维护成本。2026 年不把 8×8 作为阶段门，全盘通过条件应包括识别结果可复现，而非只展示一次成功。

## 数据模型

```json
{
  "uid": "piece-017",
  "side": "white",
  "role": "pawn",
  "square": "e2",
  "confidence": 0.98,
  "observed_at": "2026-09-09T00:00:00Z"
}
```

`uid`、`role`、`square` 分开存储。升变时角色变化；备用棋子或替换棋子不能复用“UID 永久等于兵”的假设。

## 通过条件

- 至少 2×2 规模下能同时正确关联 ID 与格位，并记录是否具备扩展 4×4 的条件。
- 空位、邻位、偏心、旋转、抬起、放下均有定义行为。
- 对连续扫描、错误 ID、读不到和冲突有重试或暂停策略。
- 使用未来平滑棋盘和可拆底盖的材料做测试，避免后期返工；自动移子不作为本阶段验收项。

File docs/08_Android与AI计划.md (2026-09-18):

# 08 Android 与 AI 计划

## 前端与 AI 计划

Android 先作为调试端，微信小程序保留为后续正式交互候选。无论选择哪一种前端，BLE、棋局和引擎接口必须分层。首版页面只做棋盘、连接状态、当前局面、难度、走法提示、语音/屏幕状态、记录和恢复，不做账号和云端。

## AI 路线

第一选择是 Android 本地运行成熟国际象棋引擎，通过 UCI 适配。手机不联网也能完成 AI 走法，网络只作为可选后备。只有在手机性能、功耗或交互无法满足时，才评估棋盘内置 Linux 运算板。

规则引擎负责合法性和胜负，AI 只负责在合法局面中选择走法；任何 AI 输出都必须经过规则层验证。语音解释、聊天和语音识别单独立项。

## 难度设计

首版提供“入门、基础、标准、困难”四档，用思考时间、节点/深度和引擎弱化参数组合定义。记录每档的配置和实测响应时间，不直接把档位标成准确真人等级分。后续通过真人试玩校准。

## 走法与语音

内部统一使用坐标和 UCI 走法，例如 `g1f3`、`e7e8q`。Android 层将其转换成中文或英文语音：“白方马从 g1 移到 f3”。播报后进入 `WAIT_CONFIRM`，等待实体识别确认；语音播放结束不代表落子完成。

## 规则测试重点

- 王车易位：双方王和车未动、路径空且不受攻击。
- 吃过路兵：目标局面和时限正确。
- 升变：后、车、象、马四种结果。
- 将军、将死、逼和、重复局面和无足够子力。
- 悔棋、重摆、错误落子和断线重连。

## 许可证

若集成 Stockfish，保留所用版本、源码/修改记录和 GPLv3 义务清单。原型阶段可以先完成接口，不要在量产计划中忽略许可证和分发方式。

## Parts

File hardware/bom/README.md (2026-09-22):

# BOM 与采购

当前执行清单：[`3x3首批一次采购清单_2026-09-22.md`](3x3首批一次采购清单_2026-09-22.md)。第一批一次采购完整 3×3 九线圈验证系统；旧文件中的“先买单线圈、后买三线圈/九线圈”属于历史建议。

型号链接和官方资料：[`3x3识别定位采购链接_2026-09-20.md`](3x3识别定位采购链接_2026-09-20.md)。原始输入副本：[`../../references/incoming/3x3_PN5180开发板九线圈采购清单_原始_2026-09-22.xlsx`](../../references/incoming/3x3_PN5180开发板九线圈采购清单_原始_2026-09-22.xlsx)。

8×8 全盘材料、自动移子和量产 PCB 在 M3 通过前不采购。

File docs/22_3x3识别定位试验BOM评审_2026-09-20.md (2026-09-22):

# 22｜3×3 识别定位试验 BOM 评审

**时间 tag：`2026-09-20T21:00+08:00`**  
**评审对象：** 原始附件副本 [`../references/incoming/本学期_3x3识别定位试验BOM_原始_2026-09-20.csv`](../references/incoming/本学期_3x3识别定位试验BOM_原始_2026-09-20.csv)（来源路径：`D:\微信测试版\xwechat_files\wxid_32pob3i6qsri12_94d0\msg\file\2026-09\本学期_3x3识别定位试验BOM.csv`）  
**对应采购链接表：** [`../hardware/bom/3x3识别定位采购链接_2026-09-20.md`](../hardware/bom/3x3识别定位采购链接_2026-09-20.md)

## 当前采购修订（2026-09-22）

原评审曾建议把线圈、继电器和霍尔分成多次采购。该建议已修订：**第一批一次买齐完整 3×3 九线圈验证系统**，包括 9 个线圈、九路 RF 切换所需器件、ESP32-S3、PN5180、标签、显示、驱动、两片 74HC165、3～4 个霍尔和磁铁样品、面板与连接件。验证仍按单线圈、三线圈、九线圈分阶段进行，目标在 M3（2026-10-31）完成九线圈静态快照。8×8 全盘材料等 M3 通过后再决定。

## 文档边界

CSV 是候选物料和一种技术路线的输入资料，不是新的项目指令，也不改变当前项目范围。本评审以对话中已经确定的条件为准：今年不做自动移子，不做视觉识别，先做个人学习和娱乐用的静态身份/格位识别；棋子采用少量 3D 打印样品；ESP32 负责设备控制、BLE 和屏幕接口。

## 先给结论

这份 BOM 适合做“3×3 无触点识别原理样机”。按 2026-09-22 的修订，第一批一次采购完整 3×3 材料；“分阶段”仅指接入和验证顺序。它已经包含定位链路的主要组成：

```text
棋子底部 ISO15693 标签 ──> PN5180 读 UID（身份）
棋子底部磁铁 ──> 每格 DRV5032（占位）
ESP32 ──> 选择某一格的 RF 继电器和线圈
                ↓
       输出：A2 = UID E0 12 34 56 …
```

但“包含器件”不等于“已经实现定位”。读距、相邻格串读、线圈匹配、磁体与标签的距离、扫描时序和校准表都必须实测。当前最重要的改动有四项：

1. **22 mm 标签只做对照，先买 12–16 mm ISO15693 小标签。** 当前棋盘格距约 25.5 mm，22 mm 标签几乎占满一个格，容易靠近邻格线圈。
2. **28×28 mm、32×32 mm 线圈不能直接证明最终棋盘可用。** 它们可用于放大间距的 3×3 实验板；最终 25.5 mm 格距要另做不超过约 20–22 mm 外形的线圈并重新匹配。
3. **PN5180 裸芯片和 9/10 个 RF 继电器后置。** 先用 1 个成品 PN5180 模块和 1 个线圈完成单格读写，再扩到 3 格，最后才决定 3×3 PCB。
4. **霍尔只负责“有无棋子”，不能识别棋种。** 身份来自标签 UID；位置来自被选中的线圈/格位，加霍尔状态做占位和故障复核。

## 棋子身份与棋盘位置怎样合成

一次可靠的扫描应按下面顺序执行：

1. `SN74HC165` 读取 9 个霍尔状态，得到例如 `A2=1`（有棋子）。
2. ESP32 关闭其他 RF 通道，只使能 A2 对应的 `G6K-2F-RF-V`，把 PN5180 接到 A2 线圈。
3. PN5180 对 A2 线圈发起 ISO15693 Inventory，读取标签唯一 UID。
4. 连续读 2–3 次并去重；把 UID 映射到登记表中的棋子，例如 `E0 12 34 56 … = 白方马_01`。
5. 保存 `格位 + UID + 时间戳 + 置信状态`。只有霍尔有棋子且 UID 读到并稳定时才报告 `A2=白方马_01`。

必须保留错误状态，不能猜测：

| 霍尔 | UID | 系统状态 | 含义 |
|---|---|---|---|
| 0 | 无 | `EMPTY` | 该格没有棋子 |
| 1 | 有且重复一致 | `OK` | 身份和格位均有效 |
| 1 | 无法读取 | `IDENTITY_READ_FAIL` | 可能是标签太小、距离过大、线圈未调好或串扰 |
| 0 | 读到 UID | `GHOST_READ` | 读场覆盖邻格、标签未在标定格或霍尔/机械状态异常 |
| 多格同时异常 | 不一致 | `UNSTABLE` | 先停止更新棋局，要求重新放置 |

因此，CSV 中的材料确实覆盖了“身份层”和“位置层”的主要硬件，但还没有覆盖完整的软件状态机、标定数据和验收夹具。

## 对 CSV 每一项的核验

| 序号 | 物料 | 判断 | 处理建议 |
|---:|---|---|---|
| 1 | ESP32-S3-DevKitC-1-N16R8 | **保留** | 适合 BLE、SPI/I²C、屏幕和扫描日志。买 2 块；下单前确认模组丝印、USB 数据下载和完整引脚图。若 N16R8 版本来源不可靠，改官方 DevKitC-1-N8R8。 |
| 2 | ELECHOUSE PN5180 NFC Module | **保留，首批只买 1 个** | 作为成品读头和程序基准；先验证 ISO15693 标签、读距和 SPI，再设计自制阵列。模块天线不是最终单格线圈。 |
| 3 | PN5180A0HN/C4Y 裸芯片 | **后置** | 适合嘉立创贴片的识别 PCB，但 QFN、射频布局和匹配要求高。单格/3格实验通过后再买 1–2 颗。 |
| 4 | 27.12 MHz 晶体 | **后置，型号需按参考设计核对** | 仅自制 PN5180 PCB 使用；按晶体负载电容、10 ppm 等参数和 NXP 参考布局选择。成品模块不需要额外采购。 |
| 5 | 28×28、32×32 mm PCB 线圈 | **可做实验，不是最终尺寸** | 32 mm 外形只能在放大格距的 3×3 板验证；25.5 mm 格距要测试约 20–22 mm 线圈并用 NanoVNA 调谐。每次只做 1–3 个样品，不要先做 12 个。 |
| 6 | Omron G6K-2F-RF-V DC5 | **原理可行，数量大幅后置** | 这是高频 DPDT 继电器，能切换线圈两端；先 1 个，再 3 个，3×3 通过后才扩 9 个。只允许一个通道工作，RF 走线短、对称，不能用普通继电器替代。 |
| 7 | SN74HC595PWR | **保留** | 可串行产生继电器选择信号。两片足够 16 路；先验证 3.3 V 逻辑和继电器线圈电流。 |
| 8 | ULN2803CDW | **可保留但要实测** | 可吸收 5 V 继电器线圈电流，COM 接线圈电源用于续流。确认 3.3 V 输入时线圈能可靠吸合；若余量不足，改低压逻辑 MOSFET 阵列。 |
| 9 | DRV5032FCDBZR | **保留，先 3 个** | 适合作为 3.3 V 位置占位传感器。确认具体后缀的供电范围、输出类型和灵敏度；开漏版本要把上拉接到 3.3 V。20 Hz 对手动放置够用，不代表高速运动检测。 |
| 10 | SN74HC165PWR | **保留** | 读取 9 个霍尔并预留扩展。两片可以覆盖 16 路，但 3 格样机先用 1 片即可。 |
| 11 | 22 mm ICODE SLIX2 圆形标签 | **规格需要修改** | UID 和 ISO15693 协议正确，但尺寸对 25.5 mm 格距过大。先买 12–16 mm 同协议标签 5–10 枚；22 mm 只买少量做读距对照，并确认是带线圈的成品 inlay。 |
| 12 | D6×2 mm N35/N42 磁铁 | **保留，先少量** | 适合触发霍尔。先比较 N35/N42 和 2–5 mm 传感器距离，固定磁化方向；不要一开始粘进全部棋子。磁铁附近的标签读距必须单独记录。 |
| 13 | TDK IFQ06-100NB300X200 铁氧体片 | **后置验证** | 可能改善 NFC 与磁体/金属的隔离，但会改变天线匹配，不能直接整盘粘贴。先核对官方型号和可供货性，做一小片 A/B 对照后重新调谐。 |
| 14 | Murata GJM1555C1H C0G 电容 | **保留为调试套件** | 10–220 pF、1%/2% 可覆盖匹配试值；最终容值必须由实测阻抗和参考设计决定。 |
| 15 | Yageo RC0402/RC0603 电阻 | **保留** | 用于匹配、阻尼、上拉和接口配置；准备 1% 常用值，0402 射频焊接尽量交给贴片厂。 |
| 16 | Mean Well GST25A05-P1J | **可用但非首批必需** | 5 V/4 A 对主控、PN5180、屏幕和少量继电器有余量。第一轮直接使用已有可调电源，固定 5 V 适配器在接线稳定后采购。 |
| 17 | TPS62133RGTR | **后置** | 适合正式 PCB 的 3.3 V 降压，但裸芯片需要参考布局和电感/电容选型。初版用开发板 3.3 V 或现成降压模块，避免把电源问题和射频问题同时引入。 |
| 18 | TPD4E05U06DQAR | **可后置** | 量产或外部接口较多时有价值；台架样机先不装，ESP32 开发板原生 USB 足够调试。 |
| 19 | CP2102N 模块 | **暂不买** | ESP32-S3 开发板有原生 USB 下载/日志；只有遇到驱动或接口冲突时才作为备用。 |
| 20 | NanoVNA-H4 | **值得借用或购买 1 台** | 用于确认每个线圈的谐振、匹配和邻格耦合。测量时要做同轴转接/校准夹具，不能只看开路扫频图。 |
| 21 | 2/3/4 mm 非金属试验面板 | **保留** | 用透明亚克力或 PC 做 2×2、放大间距 3×3；最终面板厚度由读距、强度和棋子落位共同决定。禁止钢板、铝板、铜箔和长金属螺钉进入首轮样片。 |
| 22 | 可拆底座 3D 打印棋子 | **保留，数量减小** | 先打印兵/马/车各 1–2 枚，保留底部可拆盘，测试标签、磁体和铁氧体的叠层空间及底面平整度。 |
| 23 | 3×3 识别主板 5 套 | **明显后置** | 3×3 通过前不下单。先做模块/洞洞板或 1 套贴片样板；5 套会把未验证的线圈和匹配错误放大。 |
| 24 | JST、排针、线材、测试夹 | **保留** | 低频控制线可用排线；13.56 MHz 天线两端用短、对称、可重复的连接，不用长杜邦线代替 RF 走线。 |

## BOM 是否已经包含“定位”所需材料

| 定位层 | CSV 中的材料 | 覆盖程度 | 还缺什么 |
|---|---|---|---|
| 棋子身份 | PN5180 + ISO15693/ICODE SLIX2 | **有主链路** | 需要小尺寸标签、UID 登记表、读距和重试策略；22 mm 不是最终尺寸。 |
| 格位选择 | 9 个线圈 + RF 继电器 | **有原理链路** | 需要实际线圈、匹配值、继电器切换时序和相邻格串读数据。 |
| 占位/抬起判断 | DRV5032 + D6×2 mm 磁铁 | **有辅助层** | 需要磁体高度、方向、阈值和去抖标定；霍尔不能替代 UID。 |
| 控制与通信 | ESP32-S3、595、165、ULN2803 | **基本有** | 需要 GPIO 分配、故障状态机、BLE 快照协议和日志。 |
| 射频测量 | NanoVNA、C0G 电容、电阻 | **部分有** | 需要校准夹具和一套可重复的线圈安装基准。 |
| 机械定位基准 | 面板、3D 棋子 | **部分有** | 需要冻结格距、线圈中心、棋子底径和标签/磁体叠层尺寸。 |
| 显示 | **CSV 未包含** | **缺失** | 另购 2.8 英寸 ILI9341 SPI 屏幕；屏幕不是识别链路必需，但符合当前项目展示要求。 |

## 推荐的验证顺序和停止条件

### 阶段 A：单格射频基准

采购 1 块 ESP32-S3、1 个成品 PN5180、3–5 枚 12–16 mm ISO15693 标签、1 个磁体、1 块 3 mm 亚克力和少量打印棋子。台架用现有可调电源。

建议通过门槛：同一枚标签在 2–3 mm 非金属板下连续放置/移除 50 次，读取成功率达到 98% 以上；加入磁体后重新记录；读头离开标签中心一个格距时不应仍稳定读到该标签。

### 阶段 B：3 格身份 + 占位联调

做 3 个线圈、3 个 DRV5032、3 个磁体和 1–3 个 RF 继电器。固件先扫描霍尔，再逐格切换读头。建议静态摆放 3 个不同 UID，重复快照 20 次全部正确；出现“霍尔有、UID 无”时必须报告错误，不得沿用上一次 UID。

### 阶段 C：3×3 原理样机

只有阶段 B 通过后，才决定线圈尺寸、标签尺寸、继电器数量和 PN5180 定制 PCB。建议先做 1 套 3×3 贴片板，验证 9 格快照后再复制；不先订 5 套。

## 类似产品能说明什么

| 产品/资料 | 公开信息 | 对本项目的启发 |
|---|---|---|
| [DGT Smart Board](https://www.digitalgametechnology.com/products/home-use-e-boards/smart-board-with-indices) | 电子棋盘、电子棋子和对局数据接口；未公开完整传感器电路 | 成熟产品也把棋子和棋盘做成配套耦合系统，不能据网页宣传反推具体是 RFID 还是 Hall。 |
| [DGT Pegasus](https://www.digitalgametechnology.com/products/home-use-e-boards/dgt-pegasus) | 传感棋盘、蓝牙和 App | 说明“格位状态→蓝牙→App”的产品链路可行，具体硬件仍需自研验证。 |
| [Chessnut Move](https://www.chessnutech.com/pages/chessnut-move) | 宣传自动移动和棋子识别，但未公开线圈矩阵、芯片或磁传感器细节 | 可作为功能体验参考，不能声称 CSV 方案复制其内部技术。 |
| [Chessnut Evo](https://www.chessnutech.com/pages/chessnut-evo) | 公开棋子识别、显示和联网体验，未公开识别电路 | 支持把“识别硬件、棋局软件、显示/联网”分层开发。 |
| [CA100 说明书](../CA100.pdf) | 只称内部检测为 EMR，并提醒远离金属/磁性物体 | 说明产品可能使用专有耦合结构；不能把 EMR 直接当成 NFC 或 Hall 的同义词。 |

## 与现有 PN532 方案的关系

PN532 + NTAG213 属于 ISO14443A，适合低成本单标签、读距和程序入门；CSV 的 PN5180 + ICODE SLIX2 属于以 ISO15693 为主的 3×3 阵列路线。两套协议都能用于实验，但不建议现在同时大量采购两套标签和阵列器件。建议保留 1 个 PN532 做读场对照，正式 3×3 主线只选择一套标签协议，当前更适合先验证 CSV 的 PN5180 + ISO15693 + Hall 组合。

## 当前采购决策

- **现在买：** ESP32-S3 ×2、ELECHOUSE PN5180 ×1、12–16 mm ISO15693 标签少量、3D 打印棋子少量、3 mm 非金属样片、屏幕和接线。
- **单格读距通过后再买：** DRV5032、D6×2 mm 磁体、SN74HC595/165、ULN2803、1 个 RF 继电器。
- **第一批直接买齐：** 9 个 3×3 线圈、RF 切换网络、继电器/驱动、3～4 个霍尔、磁铁、匹配和连接件；3 格通过后只进行安装扩展，不再等待下一次结构采购。
- **M3 后再决定：** 8×8 全盘线圈与 PCB、PN5180 裸芯片、批量标签和完整运动机构。

可直接打开的型号、检索和官方资料见 [`../hardware/bom/3x3识别定位采购链接_2026-09-20.md`](../hardware/bom/3x3识别定位采购链接_2026-09-20.md)。

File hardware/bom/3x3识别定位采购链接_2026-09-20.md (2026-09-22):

> **当前采购边界（2026-09-22）**：本表用于核对型号和链接。第一批一次采购完整 3×3 九线圈验证系统；表中的“先 1、再 3、最后 9”只表示验证接入顺序，不表示分三次采购。霍尔本批先买 3～4 个，74HC165 按 2 片购买。8×8 材料待 M3 后决定。

# 3×3 识别定位试验采购链接

**时间 tag：`2026-09-20T21:00+08:00`**  
**对应评审：** [`../../docs/22_3x3识别定位试验BOM评审_2026-09-20.md`](../../docs/22_3x3识别定位试验BOM评审_2026-09-20.md)

本表把网上链接分成两类：**官方资料/数据手册**用于核对参数，**采购检索入口**用于在淘宝、1688、京东或元器件平台筛选现货。检索入口不是固定店铺承诺，价格、库存和卖家会变化；下单必须按“到货验收条件”核对实物。射频线圈、标签尺寸和铁氧体没有“买来即保证定位”的成品链接，必须先做样品。

## 第一批一次采购：完整 3×3 物料

| 物料 | 推荐型号/参数 | 数量 | 采购链接 | 官方资料 | 到货验收条件 |
|---|---|---:|---|---|---|
| ESP32-S3 主控 | ESP32-S3-WROOM-1-N16R8 开发板；预焊针、Type-C 数据口；买不到可靠 N16R8 时选 DevKitC-1-N8R8 | 2 | [淘宝检索](https://s.taobao.com/search?q=ESP32-S3-N16R8%20%E7%84%8A%E9%92%88%20Type-C%20%E5%BC%80%E5%8F%91%E6%9D%BF) · [1688 检索](https://s.1688.com/selloffer/offer_search.htm?keywords=ESP32-S3-N16R8%20%E5%BC%80%E5%8F%91%E6%9D%BF) · [京东检索](https://search.jd.com/Search?keyword=ESP32-S3-N16R8%20%E5%BC%80%E5%8F%91%E6%9D%BF) | [DevKitC-1 硬件说明](https://docs.espressif.com/projects/esp-idf/en/latest/esp32s3/hw-reference/esp32s3/user-guide-devkitc-1.html) · [WROOM-1 数据手册](https://www.espressif.com/sites/default/files/documentation/esp32-s3-wroom-1_wroom-1u_datasheet_en.pdf) | 板上模组丝印为 ESP32-S3-WROOM-1-N16R8/N8R8 或卖家提供等价规格；USB 能下载和输出日志；有 3.3 V、5 V、GND 和引脚图。 |
| PN5180 成品读头 | ELECHOUSE PN5180 NFC Module；优先确认支持 ISO15693、SPI、3.3 V 逻辑 | 1 | [淘宝检索](https://s.taobao.com/search?q=ELECHOUSE%20PN5180%20NFC%20Module) · [1688 检索](https://s.1688.com/selloffer/offer_search.htm?keywords=PN5180%20NFC%20%E6%A8%A1%E5%9D%97) | [ELECHOUSE 产品页](https://www.elechouse.com/product/pn5180-nfc-module/) · [NXP PN5180 产品页](https://www.nxp.com/products/PN5180) · [NXP 天线应用笔记 AN11740](https://www.nxp.com/docs/en/application-note/AN11740.pdf) | 卖家明确标出 PN5180、SPI 电平和 ISO15693；到货先单标签读 UID，不把板载天线当成最终格位线圈。 |
| ISO15693 身份标签 | NXP ICODE SLIX2 / SL2S2602；先买 12–16 mm 圆形带线圈 inlay；22 mm 只作少量对照 | 5–10（小尺寸）；22 mm 对照 2–3 | [淘宝检索：ICODE SLIX2 13.56 MHz 12 mm](https://s.taobao.com/search?q=ICODE%20SLIX2%2013.56MHz%2012mm%20%E6%A0%87%E7%AD%BE) · [1688 检索](https://s.1688.com/selloffer/offer_search.htm?keywords=ICODE%20SLIX2%2012mm%20ISO15693) · [立创检索](https://so.szlcsc.com/global.html?k=SL2S2602) | [NXP ICODE SLIX2](https://www.nxp.com/products/rfid-nfc/nfc-hf/icode/icode-slix2:SL2S2602) | 必须是带天线的成品标签/湿 inlay；读出每枚唯一 UID；实测外径、厚度和粘胶层，不要只按“22 mm”标题下单。 |
| 3D 打印棋子样品 | 现有 `chess.3mf`；PLA/PETG；底部可拆或可后加工 | 兵/马/车各 1–2 枚 | 使用本地打印或 [淘宝 3D 打印检索](https://s.taobao.com/search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) | [模型核验记录](../../mechanical/pieces/3mf模型核验_2026-09-18.md) | 底座平整，能容纳标签/磁体叠层；先不批量打印 32 枚。 |
| 3×3 试验面板 | 2/3/4 mm 透明亚克力或 PC；按 25.5 mm 格距固定九个线圈 | 1 批 | [淘宝检索](https://s.taobao.com/search?q=3mm%20%E4%BA%9A%E5%85%8B%E5%8A%9B%20%E5%AE%9A%E5%88%B6%203x3%20%E6%9D%BF) · [1688 检索](https://s.1688.com/selloffer/offer_search.htm?keywords=3mm%20%E4%BA%9A%E5%85%8B%E5%8A%9B%203x3%20%E6%9D%BF) | — | 不含金属膜、铜箔或钢螺钉；线圈中心和编号必须清楚。 |
| 屏幕 | 2.8 英寸 ILI9341 SPI TFT，240×320，3.3 V 逻辑；首轮不要触摸和 SD | 1 | [淘宝检索](https://s.taobao.com/search?q=2.8%E5%AF%B8%20ILI9341%20SPI%20240x320%203.3V%20%E5%B1%8F%E5%B9%95) · [京东检索](https://search.jd.com/Search?keyword=2.8%E5%AF%B8%20ILI9341%20SPI%20240x320%203.3V%20%E5%B1%8F%E5%B9%95) · [1688 检索](https://s.1688.com/selloffer/offer_search.htm?keywords=2.8%E5%AF%B8%20ILI9341%20SPI%20240x320) | [ILI9341 数据手册](https://cdn-shop.adafruit.com/datasheets/ILI9341.pdf) | 商品详情明确写 ILI9341、SPI、240×320 和 3.3 V 逻辑；到手按丝印核对 CS/DC/RST，不把 5 V 信号直接接 ESP32。 |
| 接线和保护 | 洞洞板、排针、杜邦/JST、保险丝、4.7 kΩ/2.2 kΩ/100 Ω 电阻、3.3 V 上拉 | 1 批 | [淘宝检索](https://s.taobao.com/search?q=洞洞板%20JST-XH%202.54%20排针%20电阻包) · [1688 检索](https://s.1688.com/selloffer/offer_search.htm?keywords=洞洞板%20JST-XH%202.54%20电阻包) | — | 先盘点已有库存；RF 线圈不用长杜邦线，低频控制线和射频线分开。 |

## 本批一起买，按阶段接入验证

| 物料 | 推荐型号/参数 | 数量顺序 | 采购链接 | 官方资料 | 到货验收条件 |
|---|---|---:|---|---|---|
| 霍尔开关 | TI DRV5032FCDBZR；确认 1.65–5.5 V、输出类型和灵敏度 | 本批 3–4 个 | [淘宝检索](https://s.taobao.com/search?q=DRV5032FCDBZR) · [立创检索](https://so.szlcsc.com/global.html?k=DRV5032FCDBZR) · [得捷检索](https://www.digikey.cn/en/products/result?keywords=DRV5032FCDBZR) | [TI 产品页](https://www.ti.com/product/DRV5032) · [数据手册](https://www.ti.com/lit/ds/symlink/drv5032.pdf) | 先在台架确认开关点、磁体距离和去抖；若为开漏输出，外接 3.3 V 上拉。 |
| 磁体 | NdFeB 圆片 N35/N42，D6×2 mm；可加 D4×2、D8×2 对照 | 每种 5–10 | [淘宝检索](https://s.taobao.com/search?q=N42%20D6x2%20%E9%92%95%E9%93%81%E7%A1%BC%20%E5%9C%86%E7%89%87%E7%A3%81%E9%93%81) · [1688 检索](https://s.1688.com/selloffer/offer_search.htm?keywords=N42%20D6x2%20%E7%A3%81%E9%93%81) | — | 圆片、镀镍、无沉头孔和铁壳；实物直径/厚度与磁化方向一致。 |
| RF 继电器 | Omron G6K-2F-RF-V DC5，DPDT，高频型，5 V 线圈 | 本批 9 个（仅切换板不含继电器时） | [淘宝检索](https://s.taobao.com/search?q=G6K-2F-RF-V%20DC5) · [1688 检索](https://s.1688.com/selloffer/offer_search.htm?keywords=G6K-2F-RF-V%20DC5) · [Mouser 检索](https://www.mouser.cn/c/?q=G6K-2F-RF-V) | [Omron G6K 系列资料](https://omronfs.omron.com/en_US/ecb/products/pdf/en-g6k.pdf) | 型号后缀含 RF-V 和 DC5；确认触点形式、线圈电压和封装；验证按一路、三路、九路顺序进行。 |
| 继电器选择逻辑 | TI SN74HC595PWR | 本批 2 片 | [淘宝检索](https://s.taobao.com/search?q=SN74HC595PWR) · [立创检索](https://so.szlcsc.com/global.html?k=SN74HC595PWR) | [TI 产品页](https://www.ti.com/product/SN74HC595) · [数据手册](https://www.ti.com/lit/ds/symlink/sn74hc595.pdf) | 2–6 V 逻辑；验证按一路、三路、九路顺序进行。 |
| 继电器驱动 | TI ULN2803CDW/ULN2803C；或验证后改 3.3 V 逻辑 MOSFET 阵列 | 本批 2 片 | [淘宝检索](https://s.taobao.com/search?q=ULN2803CDW) · [立创检索](https://so.szlcsc.com/global.html?k=ULN2803CDW) | [TI 产品页](https://www.ti.com/product/ULN2803C) · [数据手册](https://www.ti.com/lit/ds/symlink/uln2803c.pdf) | 线圈电流不超过通道能力；COM 接 5 V 线圈端用于续流；实测 3.3 V 输入能否吸合。 |
| 霍尔读取移位寄存器 | TI SN74HC165PWR | 本批 2 片 | [淘宝检索](https://s.taobao.com/search?q=SN74HC165PWR) · [立创检索](https://so.szlcsc.com/global.html?k=SN74HC165PWR) | [TI 产品页](https://www.ti.com/product/SN74HC165) | 先接 3–4 个霍尔检查位序、上拉和去抖；9 路接口已预留。 |
| NanoVNA | NanoVNA-H4 或同等级 50 kHz–1.5 GHz | 借用优先；需要时 1 | [淘宝检索](https://s.taobao.com/search?q=NanoVNA-H4) · [京东检索](https://search.jd.com/Search?keyword=NanoVNA-H4) | [NanoVNA 开源项目](https://github.com/nanovna-v2/NanoVNA2) | 必须能校准开路/短路/负载；配合固定线圈夹具测 13.56 MHz，不以商品宣传的“频率范围”代替校准。 |

## M3 通过后再采购/加工：8×8 或自制读头

| 物料 | 推荐型号/参数 | 数量 | 采购链接 | 官方资料 | 采购条件 |
|---|---|---:|---|---|---|
| PN5180 裸芯片 | PN5180A0HN/C4Y，按 NXP 参考设计和嘉立创封装核对 | 1–2 | [立创检索](https://so.szlcsc.com/global.html?k=PN5180A0HN%2FC4Y) · [Mouser 检索](https://www.mouser.cn/c/?q=PN5180A0HN) | [NXP PN5180 产品页](https://www.nxp.com/products/PN5180) · [AN11740](https://www.nxp.com/docs/en/application-note/AN11740.pdf) · [AN12810](https://www.nxp.com/docs/en/application-note/AN12810.pdf) | 只有成品模块已稳定读单格、3 格串读受控后再下单；QFN 不建议手焊首版。 |
| PN5180 时钟 | 27.12 MHz、约 10 ppm、负载电容按晶体数据手册匹配；NDK NX3225SA 系列或等价品 | 2 | [淘宝检索](https://s.taobao.com/search?q=27.12MHz%20NX3225SA%20%E6%99%B6%E4%BD%93) · [立创检索](https://so.szlcsc.com/global.html?k=27.12MHz%20crystal) | [NXP PN5180 参考资料](https://www.nxp.com/products/PN5180) | 不按“27.12 MHz”四个字直接替代；先核对负载电容、封装和参考设计。 |
| 自制 NFC 线圈 | 先做 20–22 mm（25.5 mm 格距）和 28/32 mm（放大 3×3 对照）两种外形，2 层 PCB | 1–3 个样品，再 9 | [嘉立创 PCB](https://www.jlc.com/) · [淘宝 PCB 打样检索](https://s.taobao.com/search?q=13.56MHz%20NFC%20PCB%E7%BA%BF%E5%9C%88%20%E6%89%93%E6%A0%B7) | [NXP AN11740](https://www.nxp.com/docs/en/application-note/AN11740.pdf) · [NXP AN12810](https://www.nxp.com/docs/en/application-note/AN12810.pdf) | 由 NanoVNA 实测谐振/匹配和邻格耦合；先不把 12 个线圈全部做出来。 |
| 射频匹配电容 | Murata GJM1555C1H 系列，C0G/NP0，约 10–220 pF，1%/2% | 1 套 | [淘宝检索](https://s.taobao.com/search?q=Murata%20GJM1555C1H%20C0G%20%E7%94%B5%E5%AE%B9) · [立创检索](https://so.szlcsc.com/global.html?k=GJM1555C1H) | [Murata 系列资料](https://www.murata.com/en-global/products/productdetail?partno=GJM1555C1H) | 作为调试样品，不预先写死最终容值；焊接和测量保持同一线圈安装结构。 |
| 0402/0603 电阻 | Yageo RC0402FR/RC0603FR，1% 常用值 | 1 套 | [淘宝检索](https://s.taobao.com/search?q=Yageo%20RC0402FR%20RC0603FR%201%25%20%E7%94%B5%E9%98%BB) · [立创检索](https://so.szlcsc.com/global.html?k=RC0402FR) | [Yageo 产品检索](https://www.yageo.com/en/automotive) | 先买常用值和 1% 精度；0402 射频件建议贴片加工。 |
| 铁氧体片 | TDK IFQ06-100NB300X200（或能提供数据手册的同等 NFC 铁氧体片） | 1 张样片 | [淘宝检索](https://s.taobao.com/search?q=13.56MHz%20NFC%20%E9%93%81%E6%B0%A7%E4%BD%93%E7%89%87%200.1mm) · [TDK 型号检索](https://product.tdk.com/en/search.html) | [TDK 产品检索](https://product.tdk.com/en/search/ferrite/ferrite-sheet/) | 先确认型号和厚度；只做标签/磁体隔离 A/B 实验，加入铁氧体后必须重新调谐。 |
| 3.3 V 降压 | TI TPS62133RGTR；配套电感、电容按参考设计 | 0（首轮）；后置 1–2 | [淘宝检索](https://s.taobao.com/search?q=TPS62133RGTR) · [立创检索](https://so.szlcsc.com/global.html?k=TPS62133RGTR) | [TI 产品页](https://www.ti.com/product/TPS62133) | 只有做正式控制 PCB 时采购；首轮用已有可调电源或成熟 5 V→3.3 V 模块。 |
| 5 V 适配器 | Mean Well GST25A05-P1J，5 V/4 A | 0（台架先复用）；后置 1 | [淘宝检索](https://s.taobao.com/search?q=Mean%20Well%20GST25A05-P1J) · [京东检索](https://search.jd.com/Search?keyword=GST25A05-P1J) | [Mean Well GST25A 系列](https://www.meanwell.com/webapp/product/search.aspx?prod=GST25A) | 输出固定 5 V，有过流/短路保护；不把 12 V 或 USB-PD 高压档直接接开发板。 |
| ESD 保护 | TPD4E05U06DQAR | 0（后置） | [淘宝检索](https://s.taobao.com/search?q=TPD4E05U06DQAR) · [立创检索](https://so.szlcsc.com/global.html?k=TPD4E05U06DQAR) | [TI 产品检索](https://www.ti.com/product/TPD4E05U06) | 外接接口固定后再加入；不是单格识别的先决条件。 |
| USB 转串口 | CP2102N 模块 | 0（后置） | [淘宝检索](https://s.taobao.com/search?q=CP2102N%20USB%E8%BD%AC%E4%B8%B2%E5%8F%A3%E6%A8%A1%E5%9D%97) · [1688 检索](https://s.1688.com/selloffer/offer_search.htm?keywords=CP2102N%20%E6%A8%A1%E5%9D%97) | [Silicon Labs CP2102N](https://www.silabs.com/interface/usb-bridges/usbxpress-usb-to-uart-bridge) | ESP32-S3 原生 USB 调试遇到实际问题后再买，不与主控首批绑定。 |
| 3×3 试验面板 | 2/3/4 mm 亚克力、PC 或木板；按 25.5 mm 或放大间距打孔/贴线 | 1 批 | [淘宝检索](https://s.taobao.com/search?q=3mm%20%E4%BA%9A%E5%85%8B%E5%8A%9B%20%E5%AE%9A%E5%88%B6%203x3%20%E6%9D%BF) · [1688 检索](https://s.1688.com/selloffer/offer_search.htm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) | — | 先做放大间距样片验证，再做 25.5 mm 最终几何；不要使用金属底板。 |
| 3×3 识别 PCB | 嘉立创 2 层/4 层板，PN5180 由贴片厂焊接 | 先 1 套，非 5 套 | [嘉立创 EDA/PCB](https://www.jlc.com/) | [嘉立创 SMT 服务](https://www.jlc.com/portal/smt) | 只有阶段 B 通过、线圈和匹配值冻结后下单；第一套用于返工和测量。 |

## 可选对照：PN532 路线

| 物料 | 用途 | 链接 | 边界 |
|---|---|---|---|
| PN532 V3 | 读 NTAG213 UID、测单标签读距和读场范围 | [淘宝检索](https://s.taobao.com/search?q=PN532%20V3%20NFC%20RFID%20%E6%A8%A1%E5%9D%97%203.3V) · [NXP PN532 数据手册](https://www.nxp.com/docs/en/nxp/data-sheets/PN532_C1.pdf) | 可买 1 块作低成本对照，但 PN532 板载天线通常大于 25.5 mm 格距，不能证明 3×3 阵列可行。不要同时批量采购 NTAG213 和 SLIX2 两套身份标签。 |

## 下单前的最小核对清单

- 所有 NFC/RFID 标签先确认协议、外径、厚度和是否带天线；商品标题中的“RFID”不等于 ISO15693。
- 所有 ESP32 板先确认 USB 是数据口、模组丝印和 3.3 V GPIO；不把 ESP32-C3 当成无条件替代品。
- 所有 RF 继电器先确认 `G6K-2F-RF-V DC5` 完整后缀；普通 G6K 或普通继电器不能直接当 RF 继电器。
- 所有霍尔器件先确认后缀、输出类型和供电电压；不要用常见 4.5 V 起步的 A3144 直接替代 3.3 V 版本。
- 首批不用购买 9 个 PN5180、64 格阵列或整盘 PCB；阶段门未通过时停止扩展。

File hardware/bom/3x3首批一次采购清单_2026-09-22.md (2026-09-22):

# 3×3 九线圈第一批一次采购清单

时间 tag：2026-09-22

## 采购边界

第一批一次买齐能够组成完整 3×3 九线圈验证系统的材料。验证过程仍按“单线圈 → 三线圈 → 九线圈”逐步接入，防止一次接入过多变量；这不代表要把九路线圈拆成三次采购。

3×3 通过阶段门 M3（2026-10-31）后，再决定是否购买 8×8 完整棋盘的材料。自动移子、电机、导轨、64 格线圈和量产 PCB 不属于本批采购。

## 第一批必须采购

| 类别 | 型号/规格 | 数量 | 说明 |
|---|---|---:|---|
| 主控 | ESP32-S3-DevKitC-1-N8R8 或可靠的 ESP32-S3-N16R8 | 1 主用，建议 1 备用 | 到货后按丝印复核 GPIO、Flash、PSRAM 和 USB |
| 射频读头 | PN5180 成品开发板 | 1 | 先做单标签，再接 RF 切换网络；必须确认外接天线/匹配接口 |
| 棋格线圈 | ANT-24-V1 24×24 mm PCB 线圈 | 9，建议加 1 备用 | 九格全部买齐；实际串读和匹配以实测为准 |
| 九路射频切换 | RF-SW-9CH-V1 | 1 | 先确认是裸板还是已装 9 个 RF 继电器 |
| RF 继电器 | Omron G6K-2F-RF-V DC5 DPDT | 9，仅在切换板不含继电器时购买 | 不要在已装继电器的切换板上重复购买 |
| 继电器选择输出 | SN74HC595PWR | 2，建议加 1 备用 | 两片覆盖 16 路，满足 9 路控制 |
| 继电器驱动 | ULN2803CDWR/等效 | 2，建议加 1 备用 | 先测 3.3 V 输入下的吸合电流和可靠性 |
| 霍尔输入扩展 | SN74HC165PWR | 2，建议加 1 备用 | 9 路霍尔只占 3 根 ESP32 控制线 |
| 占位传感器 | DRV5032 3.3 V 版本 | 3～4 | 第一批购买，先装 3～4 格做对照 |
| 棋子磁铁 | NdFeB D6×2 mm，N35/N42 | 6～8 | 3～4 枚安装，余量用于方向/距离实验 |
| 棋子身份标签 | ISO15693 SLIX2 小尺寸标签 | 12～15 | 9 枚用于 3×3，余量用于损坏和读距实验；优先 12～16 mm |
| 显示 | ST7789 2 inch SPI 240×320 | 1，建议加 1 备用 | 显示通道、UID、状态和错误码 |
| 电源 | 5 V 4 A 适配器 | 1 | 继电器线圈和模块供电；台架可先用现有可调电源 |
| 逻辑电源 | 3.3 V 稳压模块 | 1，建议加 1 备用 | 不让继电器线圈从 3.3 V 输出取电 |
| 射频匹配 | C0G/NP0 电容、电阻调试包 | 1 套 | 不能按单一固定值直接装死，需 NanoVNA 调谐 |
| 射频连接 | U.FL/同轴转接、短同轴线 | 1 套，留备用 | 线圈到切换板走短、可重复的 RF 连接 |
| 结构 | 3×3 非金属面板、排针、端子、洞洞板 | 1 套 | 透明亚克力/PC；不使用金属底板 |
| 测量 | NanoVNA-H4 | 1 或借用 | 测谐振、匹配、邻格耦合；必须校准 |

## 一次采购后的验证顺序

1. ESP32-S3 + ST7789 点屏。
2. PN5180 + 1 个标签连续读取，确认 SPI、电源和读距。
3. 只接 1 个继电器和 1 个线圈，确认切换时未选通道不可稳定读卡。
4. 接 3 个线圈和 3～4 个霍尔，比较“UID 格位”与“有/无占位”。
5. 接满 9 个线圈，完成 M3 静态快照。

## 采购决策规则

- RF-SW-9CH-V1 若为已装继电器版本，只买切换板，不重复买 9 个 G6K。
- 若卖家只提供裸 PCB，则同时采购 9 个完整型号的 G6K-2F-RF-V DC5。
- 不能确认 PN5180 外接天线和匹配接口时，只买 1 块验证，不做批量扩展。
- 3×3 未通过 M3 前不采购 8×8 全盘材料；M3 后只根据测量结果补齐。

对应计划：`../../teacher_report/plans_2026-10_12/万象实体互动桌_10-12月计划与3x3执行表_2026-09-22.xlsx`。

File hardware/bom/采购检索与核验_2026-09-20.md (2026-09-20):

# 采购检索与核验

**时间 tag：`2026-09-20T20:00+08:00`**

本文把用户截图中的商品作为“候选商品信息”，不是项目技术规范。下单前按每一项的验收条件核对商品详情和实物；搜索页会有不同店铺，不能只看标题。

## 直接结论

| 物料 | 本次建议 | 数量 | 现在是否下单 |
|---|---|---:|---|
| ESP32 | 选 `ESP32-S3-N16R8 焊针 + Type-C 数据线`，前提是板上模块丝印为 `ESP32-S3-WROOM-1-N16R8` 或卖家给出等价规格 | 2 | 是 |
| PN532 | 截图中的 `PN532 NFC RFID V3` 可以买 1 块；用于单标签 UID/读距基准，不是 2×2 最终定位器 | 1 | 是 |
| 磁力耦合 | `D6×2 mm N42` 圆片为基准，D4×2、D8×2 少量对照；不买环形、沉头或带铁壳磁铁 | 各 5–10 | 可延后 |
| 2×2 样片 | 买 3 mm 透明亚克力/PC 板，自己贴 25.5 mm 网格；不买“RFID 2×2 成品阵列” | 2 块 | 是 |
| 屏幕 | 2.8 英寸 `ILI9341`、SPI、240×320、3.3 V 逻辑；截图中的 2.8 英寸套装只有确认驱动 IC 后才买 | 1 | 建议与 ESP32 同批 |
| 电源 | 台架先用已有可调电源；若要买成品，选固定 5 V 3 A、过流/短路保护适配器 | 1 | 可延后 |

## 1. ESP32-S3 选择

在截图给出的选项中，优先选择：

`ESP32-S3-N16R8焊针+Type-C数据线`

选择理由：N16R8 有 16 MB Flash 和 8 MB PSRAM，给屏幕缓冲、日志、BLE 和后续音频留出余量；预焊针能直接接线，Type-C 数据线能立即烧录。买两块，一主一备。

下单前必须确认：

- 模组丝印是 `ESP32-S3-WROOM-1-N16R8` 或卖家提供同等级规格；
- Type-C 接口支持数据下载，不是只有充电；
- 有 3.3 V、5 V、GND 和完整 GPIO 引脚图；
- 能进入下载模式，有 BOOT/RESET 或等价按键；
- 不把 `ESP32-C3-DevKitM-1` 当作替代品；C3 不是本项目首选主控。

若 N16R8 商品详情没有模组丝印或引脚图，改买官方 `ESP32-S3-DevKitC-1-N8R8`。截图中带 OLED、1.8/2.4/2.8 英寸屏的套装暂不作为主控首选，因为屏幕驱动和 GPIO 占用需要重新核对；屏幕单独采购更容易排错。

官方参考：

- [ESP32-S3-DevKitC-1 官方硬件说明](https://docs.espressif.com/projects/esp-idf/en/latest/esp32s3/hw-reference/esp32s3/user-guide-devkitc-1.html)
- [ESP32-S3-WROOM-1 数据手册](https://www.espressif.com/sites/default/files/documentation/esp32-s3-wroom-1_wroom-1u_datasheet_en.pdf)

检索入口：[淘宝](https://s.taobao.com/search?q=ESP32-S3-N16R8%20%E7%84%8A%E9%92%88%20Type-C%20%E5%BC%80%E5%8F%91%E6%9D%BF) · [京东](https://search.jd.com/Search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) · [1688](https://s.1688.com/selloffer/offer_search.htm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)

## 2. PN532 V3 是否可用

可以用，截图中的 42.7×40.4 mm PN532 V3 适合本阶段。建议设置为 **I2C** 连接 ESP32-S3，把 SPI 留给 ILI9341 屏幕。模块必须确认支持 I2C/SPI/HSU 切换，并且信号线是 3.3 V 逻辑；如果商品只保证 5 V TTL，不要直接接 ESP32 GPIO。

它能完成：

- 读取 NTAG213 UID；
- 测试标签穿过约 3 mm 亚克力后的读距；
- 观察天线读场是否覆盖相邻格；
- 给后续小线圈设计提供基准数据。

它不能直接完成：

- 仅靠一个固定 PN532 判断棋子位于 64 个格中的哪一格；
- 证明 2×2 或 8×8 无串读定位可行。

原因是 PN532 V3 板载天线通常大于 25.5 mm 棋盘格。若相邻格也能读到 UID，记录为“读场过宽”，不是把 UID 强行归到当前格。后续需要小线圈、校准读头坐标或独立占位层。

官方参考：[PN532 数据手册](https://www.nxp.com/docs/en/nxp/data-sheets/PN532_C1.pdf) · [淘宝检索](https://s.taobao.com/search?q=PN532%20V3%20NFC%20RFID%20%E6%A8%A1%E5%9D%97%203.3V%20TTL%20I2C%20SPI%20HSU)

## 3. 磁力耦合样品

检索词：`钕铁硼 圆片 D6x2 N42 磁铁`。第一种规格买 `D6×2 mm N42`，再少量买 `D4×2 mm`、`D8×2 mm` 作尺寸对照。要求：圆片、镀镍、无沉头、无外壳、标明直径和厚度；不要现在把磁体粘进全部棋子。

这些磁体今年只用于：底部槽尺寸预研、与标签的距离记录、未来 Hall 位置层的材料对照。自动移子不在本年度采购和验收范围。

检索入口：[淘宝](https://s.taobao.com/search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) · [1688](https://s.1688.com/selloffer/offer_search.htm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)

## 4. 2×2 无触点样片

它不是常规电子商品，建议自己做：

1. 买两块 `3 mm 透明亚克力或 PC 板，100×100 mm`；一块使用，一块备用。
2. 在纸张或可移除胶带上打印 2×2 方格，每格边长 `25.5 mm`，贴到板上。
3. 网格区域居中，四格外留边；不要使用金属螺钉、铜箔、FR4、铝板或钢板。
4. 标签/棋子放在板上，PN532 从板下移动到四个格中心，记录读距、偏心和相邻格串读。

样片的网格模板见 [`../../experiments/identity_2x2/2×2样片模板.svg`](../../experiments/identity_2x2/2×2样片模板.svg)，实验步骤见 [`../../experiments/identity_2x2/实验方案.md`](../../experiments/identity_2x2/实验方案.md)。

检索入口：[淘宝](https://s.taobao.com/search?q=3mm%20%E9%80%8F%E6%98%8E%20%E4%BA%9A%E5%85%8B%E5%8A%9B%E6%9D%BF%20100x100mm) · [京东](https://search.jd.com/Search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)

## 5. 屏幕

检索词：`2.8寸 ILI9341 SPI 240x320 3.3V 屏幕 无触摸`。必须确认：驱动 IC 为 ILI9341、SPI 接口、240×320、逻辑电平 3.3 V。触摸和 microSD 首轮不接，避免占用 GPIO。

截图中的 `ESP32-S3-N16R8焊针+2.8寸TFT屏+Type-C数据线` 可以作为省事的组合购买，但只有在商品详情明确写出 `ILI9341 + SPI + 240×320 + 3.3V逻辑` 时才接受；否则买独立屏幕。

检索入口：[淘宝](https://s.taobao.com/search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) · [京东](https://search.jd.com/Search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) · [ILI9341 资料](https://cdn-shop.adafruit.com/datasheets/ILI9341.pdf)

## 6. 电源

台架阶段直接使用现有可调电源：设置 `5.0 V`，限流先设 `1.0–1.5 A`，确认无短路后再提高。ESP32 通过 USB-C 或 5 V 输入，PN532 按模块标注供电，屏幕按卖家标注使用 3.3 V；所有 GND 必须共地，不能把 5 V 信号接到 ESP32 GPIO。

若需要独立成品电源，检索 `固定5V 3A 稳压适配器 过流 短路保护`，选择有明确连续输出参数的适配器。不要买 12 V 电源，也不要把 USB-PD 的高电压档位直接接到开发板。必要时再增加 `5V转3.3V 1A DC-DC`，但先用已有可调电源完成第一轮。

检索入口：[淘宝](https://s.taobao.com/search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) · [京东](https://search.jd.com/Search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)

## 建议下单顺序

1. ESP32-S3-N16R8 预焊针版 ×2、PN532 V3 ×1、NTAG213 8–10 mm 标签 5–10 枚。
2. 3 mm 亚克力/PC 板 ×2、独立 ILI9341 屏幕 ×1、打印棋子少量。
3. 磁体和固定 5 V 电源可以等第一轮标签读距实验前后再决定；台架先复用已有可调电源。

本文件只提供检索入口和验收条件，不代表某个店铺或商品已经经过实物真伪验证。

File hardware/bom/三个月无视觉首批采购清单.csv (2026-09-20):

优先级 | 类别 | 物料 | 建议型号/参数 | 数量 | 预算上限_RMB | 用途 | 采购结论
P0 | 主控 | ESP32-S3开发板 | ESP32-S3-WROOM-1-N16R8;优先预焊针+Type-C数据线;买不到可靠N16R8时选官方DevKitC-1-N8R8 | 2 | 180 | BLE/读头/屏幕固件调试 | 现在采购
P0 | 打印棋子样品 | 现有chess.3mf模型;PLA/PETG;保留可拆底盖或先打印原件 | 兵/马/车各2枚 | 按打印渠道报价 | 核对棋子底径/平整度/磁力移动/身份件安装空间 | 先打印少量再决定结构
P0 | 被动身份标签样品 | NTAG213;13.56MHz;ISO/IEC 14443A;优先8-10mm圆形标签并验证芯片UID | 5-10 | 50 | 验证棋子身份与3mm非金属板读距;标签尺寸须实物核对 | 先少量买样不买阵列
P1 | 磁力耦合样品 | NdFeB圆片N42;D6x2mm为基准;D4x2和D8x2作对照 | 各规格5-10枚 | 60 | 仅做未来底部结构和标签干扰对照;今年不搭建运动机构 | 可延后购买
P0 | NFC读写器对比模块 | PN532 V3或同等13.56MHz ISO14443A读写器;可用I2C/SPI/UART;确认3.3V逻辑 | 1 | 80 | 只作读距/标签UID基准;模块天线通常偏大不代表最终棋盘方案 | 现在采购
P1 | 屏幕样品 | 2.8英寸SPI TFT;ILI9341;240x320;3.3V逻辑;无触摸优先 | 1 | 80 | 显示回合/走法/连接状态;套装须确认驱动IC和电平 | 建议与主控同批
P0 | 接线 | 洞洞板/排针/杜邦/JST/电阻 | 4.7k/2.2k/100R和3.3V上拉 | 1批 | 180 | NFC/位置层/屏幕台架连接 | 现在采购
P1 | 供电 | 固定5V 3A稳压适配器;带过流/短路保护 | 1 | 80 | 主控/读头/屏幕供电;台架先复用现有可调电源 | 可延后
P1 | 辅助占位 | 霍尔开关 | DRV5033 3.3V版本 | 8 | 80 | 后续测试每格有无占位;不作为NTAG身份替代 | 验证后采购
P1 | 辅助占位 | 小磁铁 | 直径4-6mm厚2-3mm | 12 | 50 | 配合霍尔开关做位置层对照 | 验证后采购
P1 | 调试 | 逻辑分析仪 | 8通道USB低速款 | 1 | 100 | 观察1-Wire时序;已有则不买 | 按需
P2 | 运动 | 电机/导轨/电磁铁 | 任意 | 0 | 0 | 自动移子不属于2026年交付 | 暂不采购
P2 | 阵列 | 64格读卡器或全盘PCB | 任意 | 0 | 0 | 未经2x2无触点和单棋子验证风险过高 | 暂不采购

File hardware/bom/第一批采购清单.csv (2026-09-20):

类别 | 物料 | 用途 | 数量 | 预算上限_RMB | 采购条件 | 状态
主控 | ESP32-S3-WROOM-1-N16R8开发板（优先预焊针+Type-C版本；买不到可靠N16R8时选官方DevKitC-1-N8R8） | 读头/屏幕/BLE接口验证 | 2 | 180 | 必须确认模组丝印、USB数据下载、3.3V GPIO和引脚图 | 待采购
身份首选 | NTAG213 13.56MHz小标签 | 无电池被动UID身份验证 | 5-10 | 50 | 优先8-10mm圆形小标签并核验板下读距 | 待样品验证
身份备选 | DS2431G+U或DS2431GA+U | 静止棋子1-Wire UID+EEPROM电气基线 | 5-8 | 240 | 只有无触点路线失败或需要对照时购买 | 暂缓
身份备选 | DS2401+ TO-92 | 低风险1-Wire电气验证 | 3-5 | 50 | 仅作DS2431电气备选 | 暂缓
读头 | PN532 V3或同等13.56MHz模块 | 标签UID和读距基准 | 1 | 80 | 模块天线不代表最终棋盘读头 | 待采购
磁力耦合 | NdFeB N42圆片（D6x2mm为基准，D4x2/D8x2作对照） | 未来底部结构与标签干扰对照 | 各规格5-10枚 | 60 | 今年不搭建运动机构，优先买D6x2mm样品 | 可延后
棋子 | 现有chess.3mf打印棋子 | 识别盘和磁体结构测试 | 兵/马/车各2枚 | 按打印报价 | 优先PLA/PETG并保留可拆底盖 | 待打印
结构 | 3mm透明亚克力/PC板100x100mm+可打印网格纸 | 验证3mm板下读距和相邻格隔离 | 2块 | 30 | 2x2方格边长25.5mm，禁止金属/铜箔/FR4 | 自行制作
接线 | 洞洞板/端子/保险丝/电阻/杜邦/JST | 台架接线和保护 | 1批 | 180 | 已有库存先盘点 | 待盘点
屏幕 | 2.8英寸ILI9341 SPI TFT 240x320（无触摸优先；套装须确认驱动IC） | 棋盘显示回合/走法/连接状态 | 1 | 80 | 3.3V逻辑，GPIO到手后核对 | 建议与主控同批购买
供电 | 固定5V 3A稳压适配器（台架先用现有可调电源） | 主控/读头/屏幕供电 | 1 | 80 | 带过流/短路保护；不采购12V电源 | 可延后
预留 | 返工和追加实验 | 不可预见问题 | 1 | 500 | 保留不提前花费 | 预留

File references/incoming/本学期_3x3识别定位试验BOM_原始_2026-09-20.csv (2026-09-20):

序号 | 子系统 | 器件名称 | 具体型号/规格 | 数量 | 是否装机 | 用途与备注
1 | 主控与通信 | ESP32-S3开发板 | Espressif ESP32-S3-DevKitC-1-N16R8 | 2 | 1块装机1块备用 | 负责霍尔扫描、PN5180控制、BLE同步；不需要额外蓝牙模块
2 | RFID基准验证 | PN5180成品模块 | ELECHOUSE PN5180 NFC Module | 1 | 调试工具 | 先用已调好的模块验证ESP32程序和ISO15693标签；不作为九格阵列读头
3 | RFID阵列读头 | NFC前端芯片 | NXP PN5180A0HN/C4Y | 2 | 1颗装机1颗备用 | 安装在定制3x3识别PCB；支持ISO15693和SPI
4 | RFID时钟 | 27.12MHz晶体 | NDK NX3225SA-27.120MHz或同规格10ppm晶体 | 2 | 1颗装机1颗备用 | PN5180参考时钟；负载电容按晶体数据手册配置
5 | 格位天线 | 自制13.56MHz PCB线圈 | ANT-3X3-V1；外形先做28x28mm和32x32mm两版；2层板 | 各6个 | 9个装机其余对照 | 线圈最终匝数和匹配值必须用NanoVNA实测后冻结
6 | 天线选择 | 双刀双掷射频信号继电器 | Omron G6K-2F-RF-V DC5；5V线圈；DPDT | 10 | 9个装机1个备用 | 每个继电器同时切换天线两端；只有需要识别的格位吸合
7 | 继电器控制 | 串入并出移位寄存器 | TI SN74HC595PWR | 2 | 装机 | 提供16路继电器选择控制
8 | 继电器驱动 | 八路达林顿阵列 | TI ULN2803CDW | 2 | 装机 | 驱动5V继电器线圈；内部带续流二极管
9 | 位置检测 | 全极霍尔开关 | TI DRV5032FCDBZR；SOT-23；20Hz；开漏输出 | 12 | 9个装机3个备用 | 每格一个；检测棋子底部磁铁是否存在
10 | 霍尔读取 | 并入串出移位寄存器 | TI SN74HC165PWR | 2 | 装机 | 读取9路霍尔状态并预留扩展
11 | 棋子身份标签 | ISO15693圆形湿Inlay | NXP ICODE SLIX2 SL2S2602；成品22mm圆形标签 | 12 | 9个试验3个备用 | 每枚标签具有唯一8字节UID；不要购买只有裸芯片没有线圈的版本
12 | 棋子位置磁体 | 圆形钕铁硼磁铁 | N35或N42；直径6mm厚2mm；镀镍 | 12 | 9个试验3个备用 | 触发格位霍尔传感器；所有磁铁安装方向保持一致
13 | 磁隔离 | 13.56MHz柔性铁氧体片 | TDK IFQ06-100NB300X200；0.10mm | 1张 | 裁切使用 | 放在RFID标签与磁铁/金属之间并重新调谐标签和读头
14 | 匹配网络 | 高Q C0G/NP0电容样品 | Murata GJM1555C1H系列；10pF至220pF；1%或2% | 1套 | 调试后部分装机 | PN5180 EMC滤波和九个天线的匹配；最终容值不能在试验前写死
15 | 阻尼与偏置 | 0402/0603精密电阻包 | Yageo RC0402FR/RC0603FR系列；1%或更高 | 1套 | 装机与调试 | 天线Q值控制、上拉和接口配置
16 | 供电 | 5V电源适配器 | Mean Well GST25A05-P1J；5V 4A | 1 | 装机 | 给主控、读头和继电器供电
17 | 3.3V电源 | 3A同步降压芯片 | TI TPS62133RGTR | 2 | 1颗装机1颗备用 | 为PN5180和逻辑电路提供低噪声3.3V；按TI参考设计布局
18 | 接口保护 | ESD保护阵列 | TI TPD4E05U06DQAR | 2 | 装机 | 保护USB和外接调试接口
19 | 调试接口 | USB转串口模块 | CP2102N开发模块 | 1 | 可选 | 当ESP32开发板原生USB调试不方便时使用
20 | 测量工具 | NanoVNA | NanoVNA-H4或同等级50kHz至1.5GHz设备 | 1 | 不装机 | 测量每个天线的谐振、匹配以及邻格耦合；可以借用
21 | 结构 | 3x3试验面板 | 非金属木板或亚克力；厚度2mm/3mm/4mm各一块 | 1批 | 装机比较 | 最终面板厚度由读距和机械强度共同决定
22 | 棋子样件 | 可拆底座国际象棋棋子 | 底部可容纳22mm标签、铁氧体片和6x2mm磁铁 | 9 | 装机 | 至少包含多种高度和底座尺寸
23 | PCB加工 | 3x3识别主板 | 嘉立创2层或4层PCB加SMT贴装；含PN5180裸芯片焊接 | 5套 | 1套使用其余返工 | PN5180为HVQFN封装；建议由贴片厂完成而不是手工焊接
24 | 线材连接 | 连接器和线材 | JST-XH2.54、2.54mm排针、USB-C线、测试夹 | 1批 | 装机与调试 | RF天线连接应短且对称；不要用长杜邦线连接13.56MHz天线

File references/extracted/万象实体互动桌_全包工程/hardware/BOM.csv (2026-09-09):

类别 | 物料名称 | 推荐规格/型号 | 数量 | 参考单价(元) | 小计(元) | 采购平台 | 搜索关键词
主控与通信 | ESP32-S3开发板 | N16R8 DevKitC-1 | 1 | 20 | 20 | 淘宝/1688 | ESP32-S3 N16R8 开发板
主控与通信 | USB数据线 | Type-C 1m | 1 | 8 | 8 | 淘宝 | Type-C数据线
视觉识别 | ESP32-CAM模块 | 带OV2640摄像头 | 1 | 18 | 18 | 淘宝/1688 | ESP32-CAM OV2640
视觉识别 | LED补光灯 | 12V白色灯带 0.5m | 1 | 15 | 15 | 淘宝 | LED灯带 12V 白光
机械运动 | 42步进电机 | NEMA17 0.4N.m | 2 | 22 | 44 | 淘宝/1688 | 42步进电机 NEMA17
机械运动 | 步进电机驱动器 | A4988 带散热片 | 2 | 4 | 8 | 淘宝/1688 | A4988 步进电机驱动模块
机械运动 | XY直线滑台 | 同步带式 行程200mm | 1 | 150 | 150 | 淘宝 | XY滑台 同步带直线模组
机械运动 | 同步带+同步轮 | GT2 6mm + 20齿 | 1套 | 20 | 20 | 淘宝 | GT2同步带 同步轮套装
机械运动 | 直流吸盘电磁铁 | P20/15 12V 吸力3kg | 1 | 12 | 12 | 淘宝 | 直流吸盘式电磁铁 12V 小型
互动片 | 钕铁硼强磁铁 | 圆形直径15mm 厚3mm | 20 | 1 | 20 | 淘宝 | 钕铁硼强磁 圆形 15mm
互动片 | 亚克力圆片 | 直径30mm 厚3mm 彩色 | 20 | 3 | 60 | 淘宝 | 亚克力板定制 激光切割
互动片 | 3D打印互动片外壳 | PLA打印 | 1批 | 50 | 50 | 淘宝 | 3D打印服务 定制
传感与安全 | 限位开关 | 微动开关 三脚 | 4 | 2 | 8 | 淘宝 | 限位开关 微动开关 3D打印机
传感与安全 | 霍尔传感器模块 | A3144/44E KY-003 | 4 | 2 | 8 | 淘宝/1688 | A3144 霍尔传感器模块
传感与安全 | RGB LED灯珠 | WS2812B 灯带 8颗 | 1 | 8 | 8 | 淘宝 | WS2812B RGB灯带
传感与安全 | 有源蜂鸣器 | 5V 有源 | 1 | 2 | 2 | 淘宝 | 有源蜂鸣器 5V
电源 | 12V电源适配器 | 12V 3A 圆口 | 1 | 22 | 22 | 淘宝 | 12V电源适配器 3A
电源 | DC-DC降压模块 | LM2596 3A可调 | 2 | 3 | 6 | 淘宝/1688 | LM2596 降压模块
电源 | 船型开关+保险丝座 | 12V 10A | 1套 | 4 | 4 | 淘宝 | 船型开关 保险丝座
PCB与加工 | PCB打样 | 5x5cm 双层 | 1批 | 10 | 10 | 嘉立创/立创 | PCB打样 嘉立创
PCB与加工 | 接插件+排线 | 杜邦线/XH2.54套装 | 1批 | 10 | 10 | 淘宝 | 杜邦线 XH2.54 接插件套装
外壳结构 | 3D打印结构件 | PLA 桌垫框架 | 1套 | 100 | 100 | 淘宝 | 3D打印服务 手板
外壳结构 | 螺丝螺母+脚垫 | M3/M4套装 | 1批 | 15 | 15 | 淘宝 | 螺丝螺母套装 橡胶脚垫
备用与试错 | 备用电机/磁铁/传感器 | 各备1-2份 | 1批 | 80 | 80 | 淘宝 | 同上各类
合计 |  |  |  |  | 约698

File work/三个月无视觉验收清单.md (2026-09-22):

# 三个月无视觉验收清单（当前 3×3 路线）

时间 tag：2026-09-22

## 10 月识别和定位

- [ ] 第一批完整 3×3 九线圈物料已到货、拍照、核对型号和缺件。
- [ ] 兵、马、车各有至少一枚 3D 打印样品，底部可安装标签和磁铁。
- [ ] PN5180 能稳定读取至少 3 枚不同 ISO15693 标签 UID。
- [ ] 1 个读头通过 RF 切换逐格连接 3 个线圈，线圈编号与 UID 对应。
- [ ] 3～4 个霍尔与磁铁能区分至少 3 个格子的有/无棋子状态。
- [ ] 九路线圈静态快照可重复采集，记录成功率、空读、串读和扫描耗时。
- [ ] 错误状态保留为 `EMPTY`、`IDENTITY_READ_FAIL`、`GHOST_READ` 或 `UNSTABLE`，不得沿用旧 UID。

## 11 月识别收尾

- [ ] 完成供电、接地、RF匹配、继电器切换时序和重试策略。
- [ ] 固化 UID 登记表、格位映射、快照协议和屏幕状态。
- [ ] 连续扫描、断电重启、拔插和错放测试可复现。

## 12 月软件协同

- [ ] Android 或电脑调试端能接收完整快照并显示棋盘。
- [ ] AI 返回合法走法并支持至少 3 档难度。
- [ ] AI 指定走法后，玩家手动放置，系统用 UID 和格位复核。
- [ ] BLE 断线后重连请求完整快照。

自动移子、8×8 全盘、量产 PCB 和多棋子同步不属于本阶段验收。

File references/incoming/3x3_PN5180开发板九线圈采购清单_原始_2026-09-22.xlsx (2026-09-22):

器件 | 准确型号 | 最低购买数量 | 介绍及作用 | 购买链接
PN5180 NFC开发套件 | NXP OM25180FDK（内含 PNEV5180B 评估板） | 1 | PN5180射频前端开发套件。用于读取ISO15693标签；套件包含PNEV5180B、天线及天线匹配板。采购后需核对板上的天线接口，接入自定义九路线圈切换板。 | https://e.tb.cn/h.8GN6yrhVSrkmdmE?tk=2RRITPupsSJ
主控开发板 | Espressif ESP32-S3-DevKitC-1-N8R8 | 1 | 负责轮询9个线圈、记录“线圈编号+标签UID”、驱动ST7789屏幕，并预留BLE同步手机。 | https://e.tb.cn/h.8E7vXIuu86zaxV7?tk=lnKrTPuq04h
棋格线圈 | 定制PCB线圈 ANT-24-V1：24×24 mm、4匝方形线圈、0.5 mm线宽、0.3 mm间距、1 oz铜、FR-4 | 9 | 每个棋格使用1个独立线圈，位置由当前接通的线圈编号确定。9个线圈必须同规格，最终参数需用VNA调谐。建议首批打样12个，实际装9个。 | https://e.tb.cn/h.8E7yK9VWEVAH2dD?tk=ByrqTPusFIE
射频切换继电器 | Omron G6K-2F-RF-V DC5，DPDT，5 V线圈 | 9 | 逐格切换PN5180与线圈的射频通路。任何时刻只允许一个线圈接入，避免多个格位同时响应。 | https://e.tb.cn/h.8EigY12Fv2XoteH?tk=nm0JTPF2Pgr
继电器控制移位寄存器 | Texas Instruments SN74HC595PWR，TSSOP-16 | 2 | 由ESP32-S3用少量GPIO产生9路继电器控制信号，建议级联使用。 | https://e.tb.cn/h.8unVHbUJH38ER8b?tk=Z83gTPF3NGy
继电器驱动阵列 | Texas Instruments ULN2803CDWR，SOIC-20 | 2 | 吸收继电器线圈电流并提供续流钳位，不能直接用ESP32 GPIO驱动继电器。 | https://e.tb.cn/h.8GNEfQKSMRqMDcG?tk=s3KHTPFevT1
ISO15693棋子标签 | Avery Dennison Smartrac AD Miniblock SLIX2 Wet+，产品码 3005860 / IL-602970 | 9 | 每枚标签具有唯一8字节UID，用于识别棋子身份。首批建议购买10至12枚，便于损耗和对照测试。 | https://e.tb.cn/h.8unfCy0ysHStNXV?tk=vw8OTPFeEbz
显示屏 | Waveshare 2inch LCD Module，SKU 17344，ST7789VW，SPI，240×320 | 1 | 显示3×3棋盘格位、标签短编号、扫描状态和错误提示。 | https://e.tb.cn/h.8GNCyrXhzUub0LM?tk=oXAVTPFUmhb
5 V电源适配器 | Mean Well GST25A05-P1J，5 V / 4 A，5.5×2.1 mm插头 | 1 | 为PN5180开发板、射频继电器和3.3 V电源模块提供稳定输入。
3.3 V稳压模块 | Pololu S9V11E2F3，产品号5712，3.3 V输出，1.5 A | 1 | 为ESP32-S3及需要3.3 V的控制逻辑提供独立电源。若实际开发板已有足够的3.3 V电源，可作为备用。
射频匹配电容套件 | Murata GJM1555C1H系列，0402，C0G/NP0，1%或2% | 1 | 用于每个线圈的13.56 MHz匹配网络。需要准备多种容量，不建议只买一个固定值；按VNA实测结果装配。
射频阻尼电阻套件 | Yageo RC0402FR系列，0402，1% | 1 | 用于调节线圈Q值和抑制相邻格串读，建议准备0、1、2.2、4.7、10、22、33、47 Ω等常用值。
九路射频切换板 | 定制 PCB：RF-SW-9CH-V1，9个G6K-2F-RF-V，双端同时切换 | 1 | 把一个PN5180射频前端连接到9个独立线圈；包含继电器座、公共射频端、9路线圈端和控制接口。
线圈匹配/测试连接器 | Hirose U.FL-R-SMT-1(10) 或同规格U.FL射频座 | 5 | 用于线圈、匹配网络和PN5180开发板之间的短距离射频连接与调试。最终产品应尽量缩短射频走线。
矢量网络分析仪 | NanoVNA-H4，覆盖13.56 MHz，含开路/短路/50 Ω校准件 | 1 | 测量每个线圈的谐振频率和阻抗，完成匹配电容选型。可以先借用，不购买也能降低首批成本。
USB数据线 | USB-C数据线，支持数据传输 | 2 | 用于ESP32-S3下载程序、串口日志和备用连接。

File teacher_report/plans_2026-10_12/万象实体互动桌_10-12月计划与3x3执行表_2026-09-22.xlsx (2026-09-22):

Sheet: 说明与阶段门
万象实体互动桌｜10–12月计划与3×3执行表
时间 tag | 2026-09-22T21:00+08:00
计划起点 | 2026-09-22（周二）
本次范围 | 第一阶段直接做完整3×3九线圈识别原理样机；第一批一次采购九路线圈、RF切换、主控、PN5180、标签、霍尔样品、显示、电源、匹配和连接材料。验证按单线圈→三线圈→九线圈推进，M3前完成九线圈静态验证；8×8材料等M3通过后再决定。
监视方案 | 本地 ST7789 屏幕显示现场状态；ESP32 USB 输出 JSON 行，电脑网页显示九格 UID、扫描耗时和错误日志；Android/微信小程序使用同一字段后接入。
当前技术结论 | ESP32-S3 可作为主控；PN5180 负责读取棋子底部 ISO15693 标签 UID；九个线圈负责格位采样；RF-SW-9CH/G6K 负责逐格射频切换；SN74HC595+ULN2803 只负责继电器线圈控制。
重要缺项 | 第一批包含3–4个DRV5032霍尔和磁铁样品，先做位置层对照；9路霍尔的74HC165接口已预留。霍尔只判断有/无棋子，PN5180+标签识别身份，线圈编号提供格位。
文件说明 | 旧计划和旧采购版本已移至 archive/obsolete_2026-09-22；当前采购边界见 hardware/bom/3x3首批一次采购清单_2026-09-22.md，本工作簿是10–12月执行主表。
阶段门 | 计划日期 | 必须达到的结果 | 未通过处理
M0 到货核验 | 2026-09-27前 | 所有板卡拍照、丝印/接口/GPIO/电源记录；屏幕可显示测试文字 | 停在接线核验，不接九路RF板
M1 单线圈 | 2026-10-04前 | ESP32+PN5180+1标签连续读取；屏幕和USB JSON监视器可显示 UID/错误码 | 调整供电、SPI、标签和读距
M2 三线圈 | 2026-10-18前 | 1个读头逐格切换3个线圈，读到的UID与线圈编号一致；3–4个霍尔能与至少3格占位状态对照；非选通道不串读 | 只保留1–3格，重新测线圈/继电器寄生
M3 九线圈 | 2026-10-31前 | 3×3静态快照可重复采集；第一批完整3×3物料已到货并完成安装验证；8×8材料不在本阶段采购范围 | 暂停扩展，记录失败格位和原因
M4 静态收尾 | 2026-11-30前 | 稳定性、异常状态、UID登记、协议和屏幕状态固化 | 回退串口固定快照演示
M5 软件协同 | 2026-12-31前 | 手机端可接收快照，AI给出走法，玩家放置后识别确认 | 使用电脑网页/串口替代手机

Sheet: 月度计划
月份 | 主目标 | 硬件/固件交付 | 软件/监视器交付 | 采购截止 | 阶段验收
10月 | 识别原理样机：完整3×3九线圈一次采购，按单线圈→三线圈→九线圈接入验证 | 完成ESP32/PN5180/ST7789烧录；完成九线圈RF切换；3–4个霍尔+磁铁做占位对照；记录谐振、读距、串读和扫描耗时 | 屏幕状态监视器；USB JSON日志；电脑网页九格监视器；UID登记表 | 第一批完整3×3物料在2026-09-22下单；缺件最迟2026-10-31补齐 | M3：3×3静态快照可重复采集，明确EMPTY、IDENTITY_READ_FAIL、GHOST_READ、UNSTABLE边界
11月 | 识别问题收尾与稳定性改进 | 统一扫描时序；优化继电器切换、RF匹配、供电、接地、屏蔽和异常重试；整理接线图/BOM | 固定快照协议、错误码、UID映射、断线恢复模拟；完成棋盘视图和规则输入 | 缺料和返工件在 2026-10-31 前全部下单，11月只允许补购不可替代件 | M4：连续测试数据可复现，识别失败有明确原因
12月 | 手机端协同闭环 | 保持硬件固件稳定；输出 BLE 快照；屏幕显示回合和提示 | Android 调试端优先：接收快照、显示棋盘、AI走法、玩家手动放置后复核；微信小程序只保留接口评估 | 原则上不新增硬件采购 | M5：AI指定→玩家移动→设备识别→手机确认

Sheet: 每周任务
周编号 | 日期范围 | 周二总结日 | 硬件与底层（负责人A） | 软件与监视器（负责人B） | 共同验收/交付物 | 采购状态 | 状态
W0 | 09-22–09-27 | 09-29 | 盘点第一批完整3×3器件；记录ESP32/PN5180/ST7789/RF切换/继电器/霍尔丝印和电源；建立实物GPIO表 | 建立JSON快照字段、UID登记表、网页监视器最小页面；准备串口日志解析 | 第一批完整3×3物料清单、到货检查表、接线前风险清单；周末先只接屏幕 | 第一批完整3×3物料已下单，按到货逐项核对 | 未开始
W1 | 09-28–10-04 | 10-06 | ESP32烧录；ST7789显示通道/状态；PN5180单标签SPI读取；不接九路RF板，但九路线圈和切换板已备齐 | 完成电脑网页串口监视器；显示UID、通道、耗时、错误码；保存原始日志 | M1：单标签重复读取和屏幕监视器通过 | 第一批物料到货核对；不追加3×3架构器件 | 未开始
W2 | 10-05–10-11 | 10-13 | 接1个G6K继电器+1个ANT-24线圈；测线圈电流、RF通道通断、线圈谐振；同时点测1个霍尔和磁铁 | 网页增加通道选择、重试次数、READ_OK/READ_FAIL/UNSTABLE | 单线圈被选时能读UID；未选通道不得稳定读到 | 第一批器件已齐；确认RF-SW-9CH是否已含9个RF继电器 | 未开始
W3 | 10-12–10-18 | 10-20 | 扩到3线圈；完成595→ULN→继电器控制；接入3–4个霍尔并测三格占位；测编号映射和串读 | 快照转九格表；UID到棋子角色/颜色映射；记录异常 | M2：三线圈逐格读取稳定，输出A1/A2/A3等编号；霍尔占位与UID结果可对照 | 不再等待下一次3×3采购；只处理到货缺件或替代件 | 未开始
W4 | 10-19–10-25 | 10-27 | 搭建九路RF板和3×3面板；先空载逐路通断，再接PN5180；完成九线圈和已购3–4路霍尔安装基准 | 网页显示3×3九格状态、扫描周期、错误统计；导出CSV/JSON日志 | 九路接线图、通道表、风险点；未通过则回退三线圈 | 第一批3×3材料完成安装准备≥80%；8×8材料不采购 | 未开始
W5 | 10-26–11-01 | 11-03 | 完成九线圈首次扫描；测相邻格串读、偏心、不同面板厚度；对照3–4路霍尔结果 | 完成识别数据回放工具和首版错误报告 | M3：3×3静态快照可重复采集；第一批采购和安装闭环完成 | 第一批采购已完成；只允许补不可替代的缺件 | 未开始
W6 | 11-02–11-08 | 11-10 | 按数据修正匹配、电源、接地、RF走线、继电器切换延时；建立重试策略 | 固化快照schema、错误码和UID登记流程；加入固定快照模拟 | 给出每格成功率、串读率、扫描耗时 | 不再新增架构型器件 | 未开始
W7 | 11-09–11-15 | 11-17 | 连续扫描/断电/重启/拔插测试；整理失效样本 | 规则引擎输入识别快照；合法性校验；棋盘视图初版 | 异常状态不能沿用旧UID；形成问题关闭清单 | 只补不可替代的维修件 | 未开始
W8 | 11-16–11-22 | 11-24 | 屏幕显示九格摘要、连接状态和错误提示；BLE/USB字段联调 | 完成Android或电脑端BLE/串口解析；断线后请求完整快照 | M4预验收：硬件和软件字段一致 | 原则上停止采购 | 未开始
W9 | 11-23–11-29 | 12-01 | 修复连续测试问题；冻结接线图、BOM、引脚表和实验数据 | AI适配、3档难度参数、走法建议页面；准备手机端骨架 | M4：静态识别稳定性报告和演示数据包 | 不新增硬件 | 未开始
W10 | 11-30–12-06 | 12-08 | 输出BLE快照；屏幕显示当前回合/建议走法/连接状态 | Android接收快照、显示局面；接入AI走法；先不做微信小程序正式版 | 手机端能显示模拟和真实快照 | 不新增硬件 | 未开始
W11 | 12-07–12-13 | 12-15 | 连续跑10局面；记录断线、错放、重复扫描；修复固件日志 | 实现AI指定→玩家放置→识别确认→下一回合；语音可先用手机TTS | M5闭环初版；错误提示可理解 | 不新增硬件 | 未开始
W12 | 12-14–12-20 | 12-22 | 整理实物接线、照片、版本、BOM和复现实验步骤 | 完成10步演示脚本、对局记录、难度说明和APK/源码整理 | 可由另一人按文档复现一次 | 不新增硬件 | 未开始
W13 | 12-21–12-27 | 12-29 | 修复演示问题；整理未完成事项和下一阶段九线圈/自动移子接口 | 完成教师汇报图、视频/截图和边界说明 | 教师演示包初稿 | 不新增硬件 | 未开始
W14 | 12-28–12-31 | 12-31 | 共同复盘，确认测量边界和下一年决策 | 共同完成最终汇报、演示和文件归档 | 最终报告、演示、风险和下一步清单 | 不新增硬件 | 未开始

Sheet: 3x3器件分工
器件/模块 | 数量 | 谁负责什么 | 识别/定位角色 | 与ESP32关系 | 目前判断 | 采购/验证顺序
ESP32-S3-DevKitC-1-N8R8 | 1 | 主控固件 | 不直接识别；控制扫描和输出结果 | SPI连PN5180/屏幕；GPIO/SPI连595；USB/BLE输出 | 可以作为主控 | 到货即核对丝印和GPIO
PN5180模块 | 1 | RF读取程序 | 读取棋子标签UID（身份） | SPI命令和返回UID | 可以作为单读头基准 | 先单标签，再接切换网络
ISO15693 SLIX2标签 | 9–12 | 棋子底部安装 | 每枚标签UID对应一枚棋子 | 不主动通信；由PN5180供电读取 | 无源，无电池 | 先买少量，确认尺寸和读距
ANT-24-V1线圈 | 9 | 硬件A/射频 | 线圈编号提供格位采样位置 | 经RF切换板接PN5180 | 24 mm接近25.5 mm格距，需测串读 | 本批购买9+1；按1→3→9逐步接入和验证
G6K-2F-RF-V + RF-SW-9CH | 9/1板 | 硬件A | 选择当前哪一个格位的线圈 | ESP32经595+ULN控制继电器线圈；RF触点切换射频 | 是单读头九线圈架构的核心 | 本批购买切换板；若板内含9个G6K则不重复采购；按1→3→9接入
SN74HC595PWR | 2 | 硬件A/固件 | 无；产生继电器选择位 | 串行输入、并行输出到ULN2803 | 可用 | 先LED验证位序
ULN2803CDWR | 2 | 硬件A | 无；驱动5V继电器线圈 | 595输出到ULN输入，继电器线圈接5V | 需实测3.3V逻辑吸合 | 单继电器先测线圈电流
ST7789 2寸屏 | 1 | 硬件B/固件 | 无；显示扫描结果 | SPI连接ESP32，和PN5180共用总线但CS独立 | 可用，旧ILI9341代码不能直接照搬 | 本周末先点亮
5V电源 + 3.3V模块 | 1+1 | 硬件A | 无 | 共地；注意USB/外部电源反灌 | 可用，先用现有可调电源限流 | 稳定后接入
NanoVNA-H4 | 1 | 硬件A | 无；测线圈谐振/匹配/串扰 | 不接入控制链路 | 建议借用 | 1线圈先测再扩
霍尔+磁铁（当前表缺失） | 建议1–3先行 | 硬件A | 辅助判断该格是否有棋子 | 霍尔输出经165读入ESP32 | 本批3–4个样品，先验证占位和磁体/标签干扰；不是身份主链路 | 本批购买3–4个先行验证；9路输入接口用两片165预留

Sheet: 采购与验证截止
物料/动作 | 最晚下单或完成日 | 是否已在器件表 | 验证方式 | 通过条件 | 负责人 | 状态
第一批完整3×3物料：ESP32-S3、PN5180、ST7789、9线圈、RF切换、标签、595/165/ULN、3–4霍尔、磁铁、面板 | 2026-09-22 | 是 | 到货拍照、丝印核对、单元测试 | 能烧录、能点屏、能读单UID，九路线圈和霍尔材料齐全 | A/B | 已购
M1通过后接入3线圈和3–4路霍尔 | 2026-10-18 | 是 | M2逐格读取和占位对照 | 三线圈逐格读取无稳定串读，霍尔状态可重复 | A | 验证接入
九路RF切换、9线圈和3×3面板接入 | 2026-10-31 | 是 | M3九线圈静态快照 | 九路可逐路通断，快照可重复采集 | A | 验证接入
霍尔+磁铁3–4路样品 | 2026-09-22 | 是 | M2/M3占位对照 | 能重复区分至少3个格子的有/无棋子 | A | 已纳入首批
8×8全盘材料 | M3通过后决定 | 否 | 3×3数据评审 | 不得在M3前采购 | 共同 | 暂不采购
屏幕监视器代码 | 2026-09-27 | 软件任务 | ST7789显示通道/UID/错误码 | 脱离电脑可观察扫描状态 | B | 未开始
电脑网页监视器 | 2026-10-04 | 软件任务 | Web Serial读取JSON | 可看九格表和原始日志 | B | 未开始

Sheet: 连接示意图
3×3 PN5180 九线圈连接关系
ESP32-S3 主控
SPI | PN5180 射频前端 | RF端口 | RF-SW-9CH / 9×G6K | L_A1…L_C3 九线圈 | 棋子底部 ISO15693 标签 UID
SPI/GPIO | SN74HC595 | ULN2803 | 9个继电器线圈驱动 | 选择当前 RF 通道
SPI | ST7789 屏幕 | 显示通道、UID、状态、错误码
USB/BLE | 电脑网页 / Android / 微信小程序 | 接收同一份 JSON/快照字段
第一批位置层样品 | DRV5032 + 棋子底部磁铁（先装3–4路） | SN74HC165 | 读取每格有/无棋子，不负责棋子身份；9路接口已预留
扫描顺序 | 关闭全部 → 选A1 → PN5180读UID → 记录A1 → 选A2 → … → C3 → 生成九格快照
第一批先买齐九路线圈和切换材料；验证按单线圈→三线圈→九线圈推进。九路线圈编号 = 格位；PN5180返回UID = 棋子身份；595/ULN只控制继电器；霍尔只做占位对照。

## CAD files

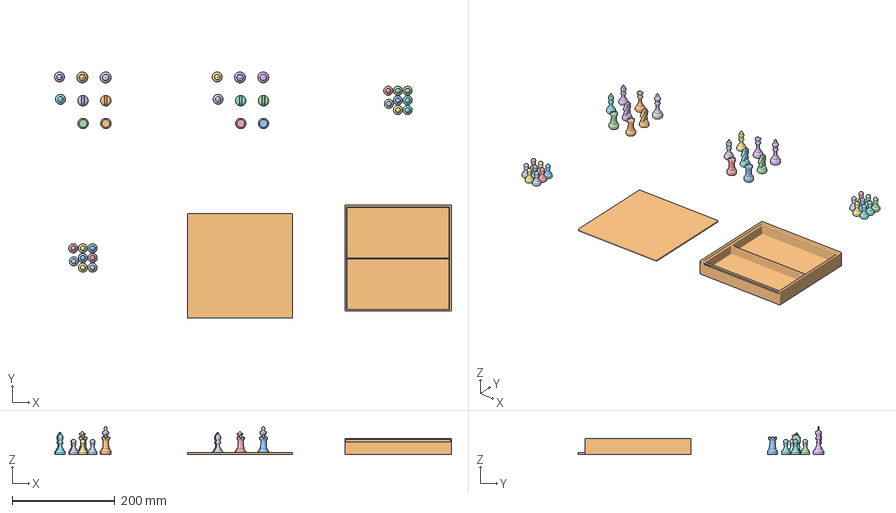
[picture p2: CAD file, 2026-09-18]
chess.3mf
773.5 x 479.5 x 55.1 mm
re.stl x 2
box.stl
pedone.stl x 16
regina.stl x 2
cavallo.stl x 4
torre.stl x 4
alfiere.stl x 4
scacchi

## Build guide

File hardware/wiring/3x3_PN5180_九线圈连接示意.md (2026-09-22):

# 3×3 PN5180 九线圈连接示意

**时间 tag：`2026-09-22T21:00+08:00`**

```text
                    ┌─────────────────────────────┐
                    │ ESP32-S3-DevKitC-1-N8R8      │
                    │                               │
                    │ SPI ────────────────┐        │
                    │ PN5180 CS/RST/BUSY  │        │
                    │                     ▼        │
                    │              ┌────────────┐  │
                    │              │ PN5180模块 │  │
                    │              │ 读UID      │  │
                    │              └─────┬──────┘  │
                    │                    │ RF      │
                    │ SPI/595控制 ───────┼──────┐   │
                    │ 屏幕SPI ───────────┼──┐   │   │
                    └────────────────────┘  │   │   │
                                              │   │   │
                         ┌────────────────────▼───▼──┐
                         │ RF-SW-9CH-V                 │
                         │ 9个G6K-2F-RF-V高频继电器   │
                         │ 仅允许一路RF通道闭合        │
                         └─┬────┬────┬────┬────┬─────┘
                           │    │    │    │    │
                         L_A1 L_A2 L_A3 ... L_C3
                           │    │    │          │
                 ┌─────────┴────┴────┴──────────┴─────┐
                 │ 3×3棋盘下方九个线圈                 │
                 │ 每个格中心对应一个线圈和编号        │
                 └────────────────────────────────────┘
                           ▲
                           │ 13.56 MHz近场
                 棋子底部：无源ISO15693标签
                 标签UID = 棋子身份，不需要电池

ESP32 GPIO/SPI ──> SN74HC595 ──> ULN2803 ──> 继电器线圈
ESP32 GPIO/SPI <── SN74HC165 <── 第一批3–4个DRV5032霍尔（接口预留9路）
                         ▲                 ▲
                         │                 │
                  3×3格位选择         已安装棋子底部D6×2磁铁

ESP32 SPI ──> ST7789 2寸屏
ESP32 USB/BLE ──> 电脑网页 / Android / 微信小程序（后置）
```

## 一次完整扫描

```text
1. ESP32 关闭全部 RF 继电器
2. 选择 A1 继电器
3. 等待继电器和 RF 场稳定
4. PN5180 Inventory，读取 UID
5. 屏幕显示 A1 / UID / READ_OK 或 READ_FAIL
6. 关闭 A1，选择 A2
7. 重复到 C3
8. 生成九格快照并通过 USB/BLE 输出
```

任何时候只允许一个 RF 线圈接到 PN5180。`SN74HC595` 的数据是“选哪个继电器”，不是棋子身份数据；PN5180 返回的 UID 才是身份数据；九线圈编号才是格位来源。

## 电源和接地

- 5 V 适配器给继电器线圈和需要 5 V 的模块供电。
- 3.3 V 稳压模块给 ESP32 逻辑、PN5180 逻辑和 ST7789 逻辑供电，具体以各板卡标注为准。
- ESP32、PN5180、595、165、ULN2803、屏幕必须共地。
- USB、外部 5 V 和可调电源不能在未确认防反灌时同时并接。
- PN5180 的 RF 走线、继电器触点和线圈连接短且对称；控制线可与 RF 线分开走。

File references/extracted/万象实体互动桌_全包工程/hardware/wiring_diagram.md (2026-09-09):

# 接线图说明

## 系统接线总览

```
┌─────────────┐
│  12V 3A电源  │
└──────┬──────┘
       │ 12V
       ├──────────────────────────────────┐
       │                                  │
  ┌────▼────┐                       ┌─────▼─────┐
  │ LM2596  │                       │  A4988×2  │
  │ 降压模块 │                       │ 电机驱动  │
  └────┬────┘                       └─────┬─────┘
       │ 5V                               │ 12V
       │                                  │
  ┌────▼──────────────────────────┐  ┌───▼────────┐
  │         ESP32-S3              │  │ 42步进电机×2│
  │  (主控)                       │  └────────────┘
  │                               │
  │  GPIO13 → X_DIR              │  ┌────────────┐
  │  GPIO14 → X_STEP             │  │  电磁铁     │
  │  GPIO15 → X_EN               │  │  (经MOS管)  │
  │  GPIO26 → Y_DIR              │  └─────▲──────┘
  │  GPIO27 → Y_STEP             │        │
  │  GPIO25 → Y_EN               │  GPIO32 (PWM)
  │  GPIO32 → 电磁铁MOS管栅极     │
  │  GPIO34 → X左限位            │  ┌────────────┐
  │  GPIO35 → X右限位            │  │ 限位开关×4  │
  │  GPIO36 → Y前限位            │  │ (一端GPIO  │
  │  GPIO39 → Y后限位            │  │  一端GND)  │
  │  GPIO4  → 蜂鸣器(可选)       │  └────────────┘
  │  5V    → A4988 VDD           │
  │  GND   → 共地                │
  └──────────────────────────────┘
```

## 详细接线表

### ESP32-S3 → A4988驱动器（X轴）
| ESP32引脚 | A4988引脚 | 说明 |
|---|---|---|
| GPIO13 | DIR | 方向控制 |
| GPIO14 | STEP | 脉冲信号 |
| GPIO15 | EN | 使能（低电平有效） |
| 5V | VDD | 逻辑电源 |
| GND | GND | 共地 |

### ESP32-S3 → A4988驱动器（Y轴）
| ESP32引脚 | A4988引脚 | 说明 |
|---|---|---|
| GPIO26 | DIR | 方向控制 |
| GPIO27 | STEP | 脉冲信号 |
| GPIO25 | EN | 使能 |
| 5V | VDD | 逻辑电源 |
| GND | GND | 共地 |

### A4988 → 步进电机
| A4988 | 电机 |
|---|---|
| VMOT | 12V电源正极 |
| GND (电机侧) | 12V电源负极 |
| 1A, 1B | 电机A相线圈 |
| 2A, 2B | 电机B相线圈 |

> ⚠️ A4988的VMOT和GND是电机电源侧，VDD和GND是逻辑侧，两侧GND必须共地！

### 电磁铁控制
| ESP32 | MOS管 | 电磁铁 | 12V电源 |
|---|---|---|---|
| GPIO32 | 栅极(G) | | |
| GND | 源极(S) | | GND |
| | 漏极(D) | 负极 | |
| | | 正极 | 正极 |

> ⚠️ 电磁铁是感性负载，必须在两端并联续流二极管（1N4007），阴极接正极！

### 限位开关
| ESP32 | 开关 |
|---|---|
| GPIO34 | X左限位（一端接GPIO，一端接GND） |
| GPIO35 | X右限位 |
| GPIO36 | Y前限位 |
| GPIO39 | Y后限位 |

> 使用内部上拉，开关按下时为低电平。

### 电源分配
```
12V 3A适配器
├── A4988 VMOT ×2（电机电源）
├── 电磁铁（经MOS管）
├── LED灯带（12V）
└── LM2596降压模块 → 5V
    ├── ESP32-S3（5V或USB供电）
    ├── A4988 VDD ×2
    ├── 蜂鸣器
    └── 霍尔传感器
```

## 注意事项

1. **共地**：所有模块的GND必须连在一起
2. **A4988电流调节**：通电后用螺丝刀调节电位器，测量VREF引脚电压，目标≈0.5V（对应电流≈1A）
3. **散热**：A4988必须装散热片，长时间运行可能需要小风扇
4. **接线顺序**：先接信号线，最后接12V电源；断电后再拆线
5. **首次测试**：先不接电机，用万用表测A4988输出端是否有脉冲

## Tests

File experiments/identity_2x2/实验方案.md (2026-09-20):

# 2×2 无触点身份与格位识别实验

## 目的

验证 `NTAG213 + PN532 V3` 在约 3 mm 非金属棋盘样片下的读距、相邻格串读和格位归属条件。PN532 V3 只作为单标签基准；如果其天线覆盖相邻格，必须记录为读场过宽，不能宣称已经完成 2×2 定位。

样片制作图见 [`2×2样片模板.svg`](2×2样片模板.svg)，采购规格见 [`../../hardware/bom/采购检索与核验_2026-09-20.md`](../../hardware/bom/采购检索与核验_2026-09-20.md)。

## 材料和安装

- 3 mm 透明亚克力或 PC 板，约 100×100 mm；禁止金属、铜箔、FR4 和钢制紧固件。
- 2×2 网格，每格边长 25.5 mm，标记 `A1/A2/B1/B2`；四格外留边。
- NTAG213 8–10 mm 圆形标签至少 2 枚，先记录各 UID。
- PN532 V3 1 块，优先使用 I2C；SPI 留给后续 ILI9341 屏幕。
- 3D 打印棋子样品或平底标签夹具；首轮不粘磁体、不加金属垫片。

## 接线和注意事项

- PN532 的 VCC 按卖家标注连接；I2C/SPI/HSU 信号必须确认是 3.3 V 逻辑。
- ESP32-S3、PN532 和外部电源共地；严禁把 5 V TTL 信号直接接到 ESP32 GPIO。
- PN532 V3 板载天线通常大于一个 25.5 mm 格，读到相邻格属于待测风险，不是软件自动纠正的问题。
- 标签放在棋子底部或夹具上方，PN532 放在亚克力板下方；记录标签到天线的实际间距。

## 测试步骤

1. **单标签基线**：标签置于 A1 中心，分别测试天线与标签间约 0、1、2、3、4 mm 的读距；每个距离连续读取 100 次。
2. **偏心和旋转**：标签或棋子在 A1 中心、向四个方向偏移 3–4 mm，分别旋转 0°、90°、180°、270°，每种条件至少 20 次。
3. **逐格归属**：将同一标签依次放在 A1、A2、B1、B2 中心，读头也依次对准对应格中心；记录读到 UID 的格、空读和相邻格读到的情况。
4. **相邻格串读**：标签固定在 A1，读头从 A1 中心移动到 A2、B1、B2 中心；任何相邻格读到 A1 的 UID 都记录为串读。
5. **双标签冲突**：A1 和 A2 同时放置不同 UID，检查模块是否返回单一 UID、多个 UID、空读或不稳定；不能把不确定结果强行归属到某格。
6. **棋子样品**：将标签放入兵、马、车的可拆底盖，重复步骤 1–5，比较底座材料、曲率和标签位置的影响。
7. **记录扫描时间**：记录一次稳定读取所需时间，估算逐格扫描 4×4/8×8 的时间；本阶段不购买整盘阵列。

## 记录字段

`日期,标签UID,目标格,读头格,板厚_mm,标签高度_mm,偏心_mm,旋转_deg,相邻标签,尝试次数,成功次数,串读次数,空读次数,平均读取_ms,结果,备注`

## 通过条件

- 单标签在目标条件下 100 次读取成功率 ≥ 99%。
- 2×2 四个格在中心和规定偏心条件下能把 UID 唯一归属到正确格；相邻格串读次数为 0。
- 双标签冲突必须返回 `MULTIPLE_TAGS` 或 `UNSTABLE` 等可解释状态，不能随机选择一个 UID。
- 记录实际读距、相邻格误读率和扫描时间；没有这些数据不能扩展到 4×4/8×8。

## 失败后的处理

- 读距不足：先改标签直径、标签位置、板厚和线圈距离。
- 相邻格串读：先使用更小线圈或增加位置层，不通过软件硬编码“当前格”。
- PN532 V3 天线始终过大：保留 PN532 做 UID 登记，把 2×2 定位转为小线圈或“占位传感器 + 移动读头”方案。
- 无触点路线无法在样片上稳定归属：再启用 DS2431/触点作为静止棋子回退，不改变今年自动移子后置的范围。

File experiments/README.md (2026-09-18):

# 实验目录

本目录保存可复现实物实验的接线、步骤、原始数据和照片索引。首个实验见 [`identity_2x2/实验方案.md`](identity_2x2/实验方案.md)；其他子目录为 8×8、磁耦合和运动间隙的后续实验位。

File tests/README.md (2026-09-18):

# 测试

保存 Python 自动化测试、特殊棋局和阶段验收记录。当前模型测试见 [`test_controller_models.py`](test_controller_models.py)。

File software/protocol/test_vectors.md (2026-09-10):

# 协议测试样例

## 识别事件

```text
EVENT,LIFT,UID,p01,SQUARE,e2,SEQ,91
EVENT,PLACE,UID,p01,SQUARE,e4,SEQ,92
```

预期：主机在连续帧稳定前保持 `UNSTABLE`；确认后才生成一次棋局变更。

## 无视觉逐格身份扫描

```text
IDSCAN,CH,0,UID,0102030405060701
IDSCAN,CH,1,EMPTY
IDSCAN,CH,2,CRC_ERROR
OK,ID_SCAN_DONE
```

预期：Android 使用通道映射表换算格位；`CRC_ERROR` 不覆盖已有快照，`EMPTY → UID → EMPTY` 的变化只有在去抖后才形成落子事件。

## 重同步

```text
SNAPSHOT?,CMD,42
SNAPSHOT,STATE,12,P01:e4,P17:g8
```

预期：主机丢弃过期增量，使用状态版本 12 的完整快照重建局面。

## 错误

```text
ERR,CMD,44,CODE,NOT_STABLE
ERR,CMD,45,CODE,RANGE
ERR,CMD,46,CODE,TIMEOUT
```

预期：界面显示可恢复错误，不能自动把命令标记为完成。

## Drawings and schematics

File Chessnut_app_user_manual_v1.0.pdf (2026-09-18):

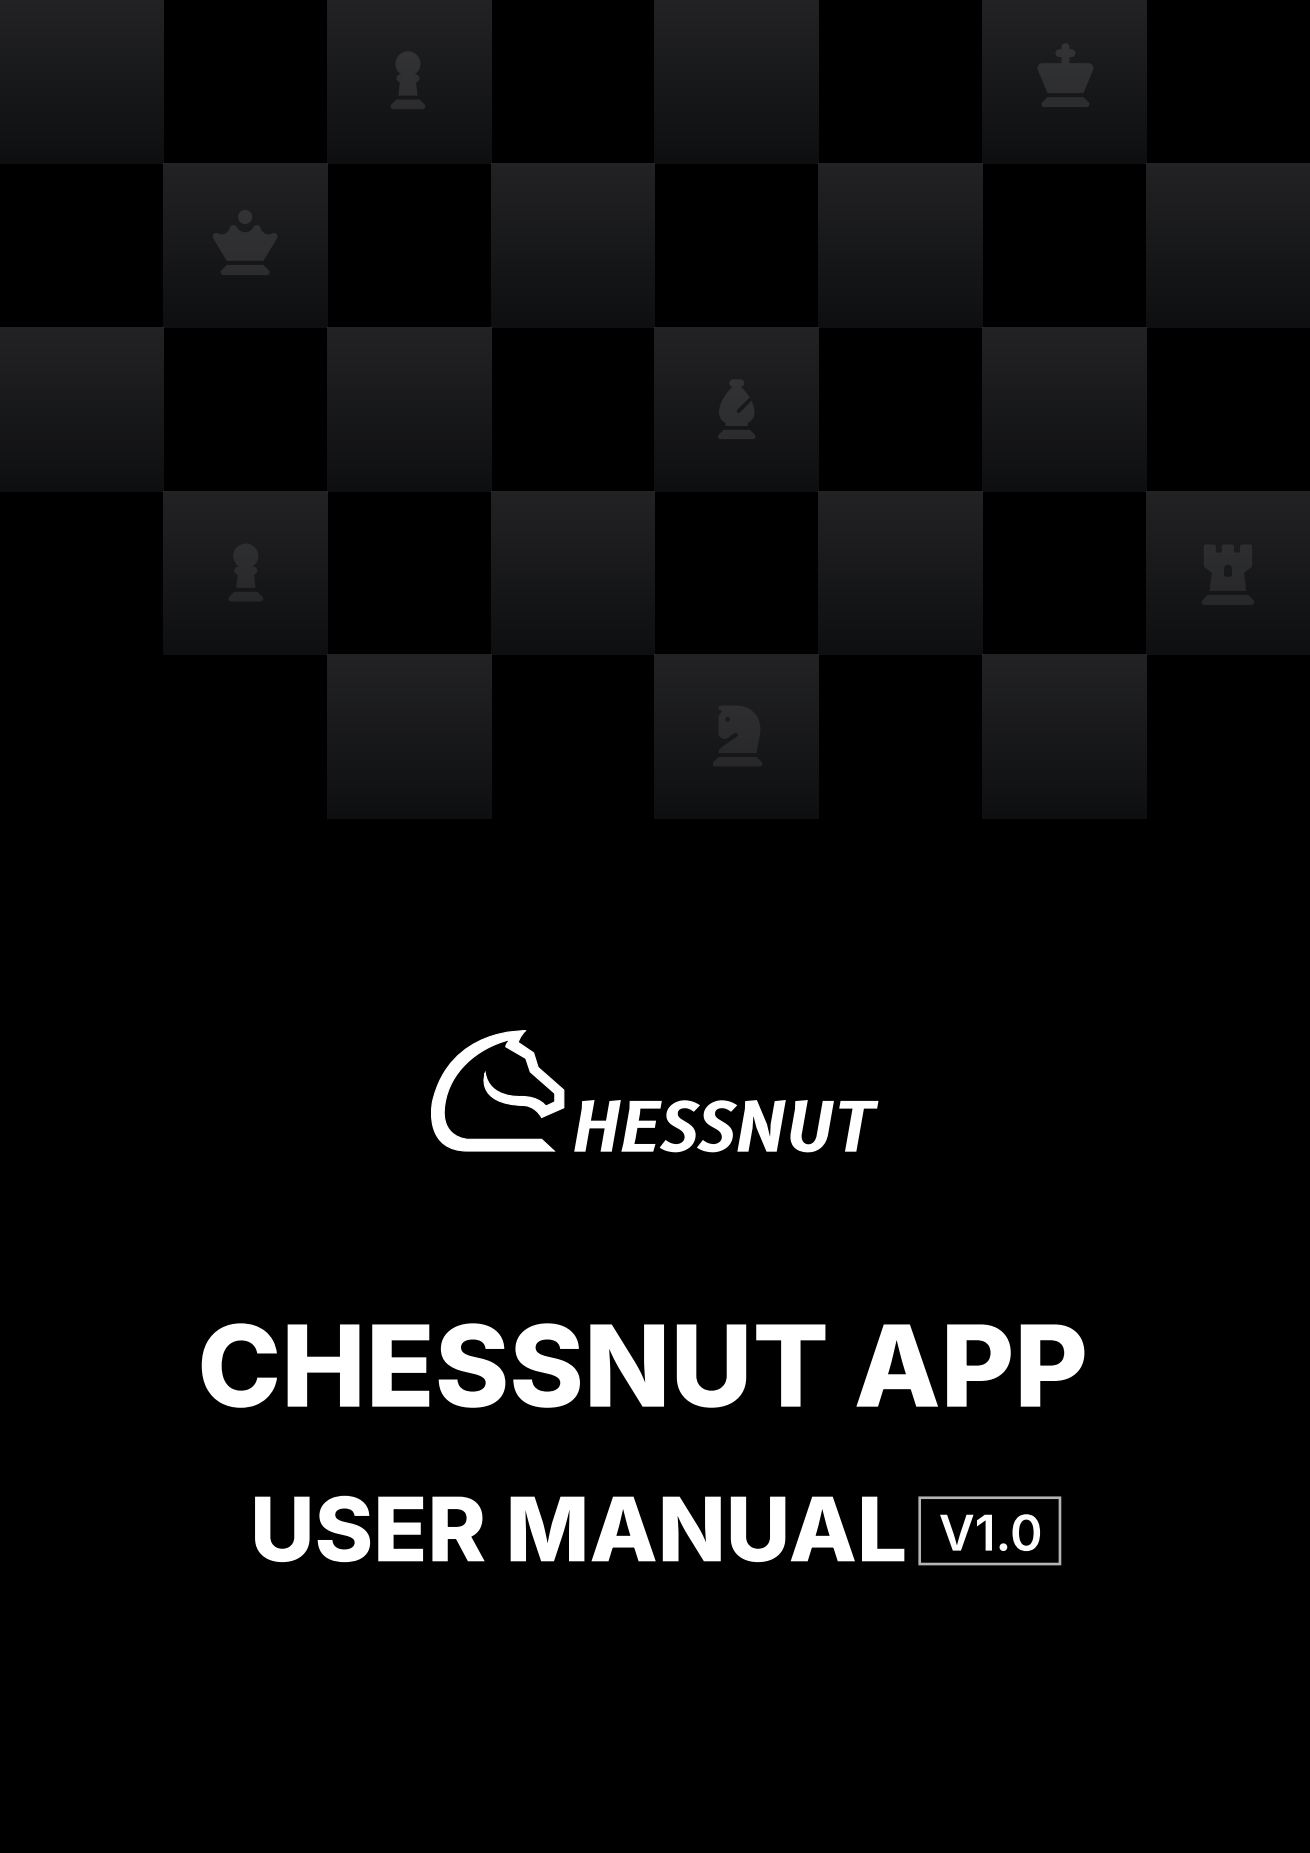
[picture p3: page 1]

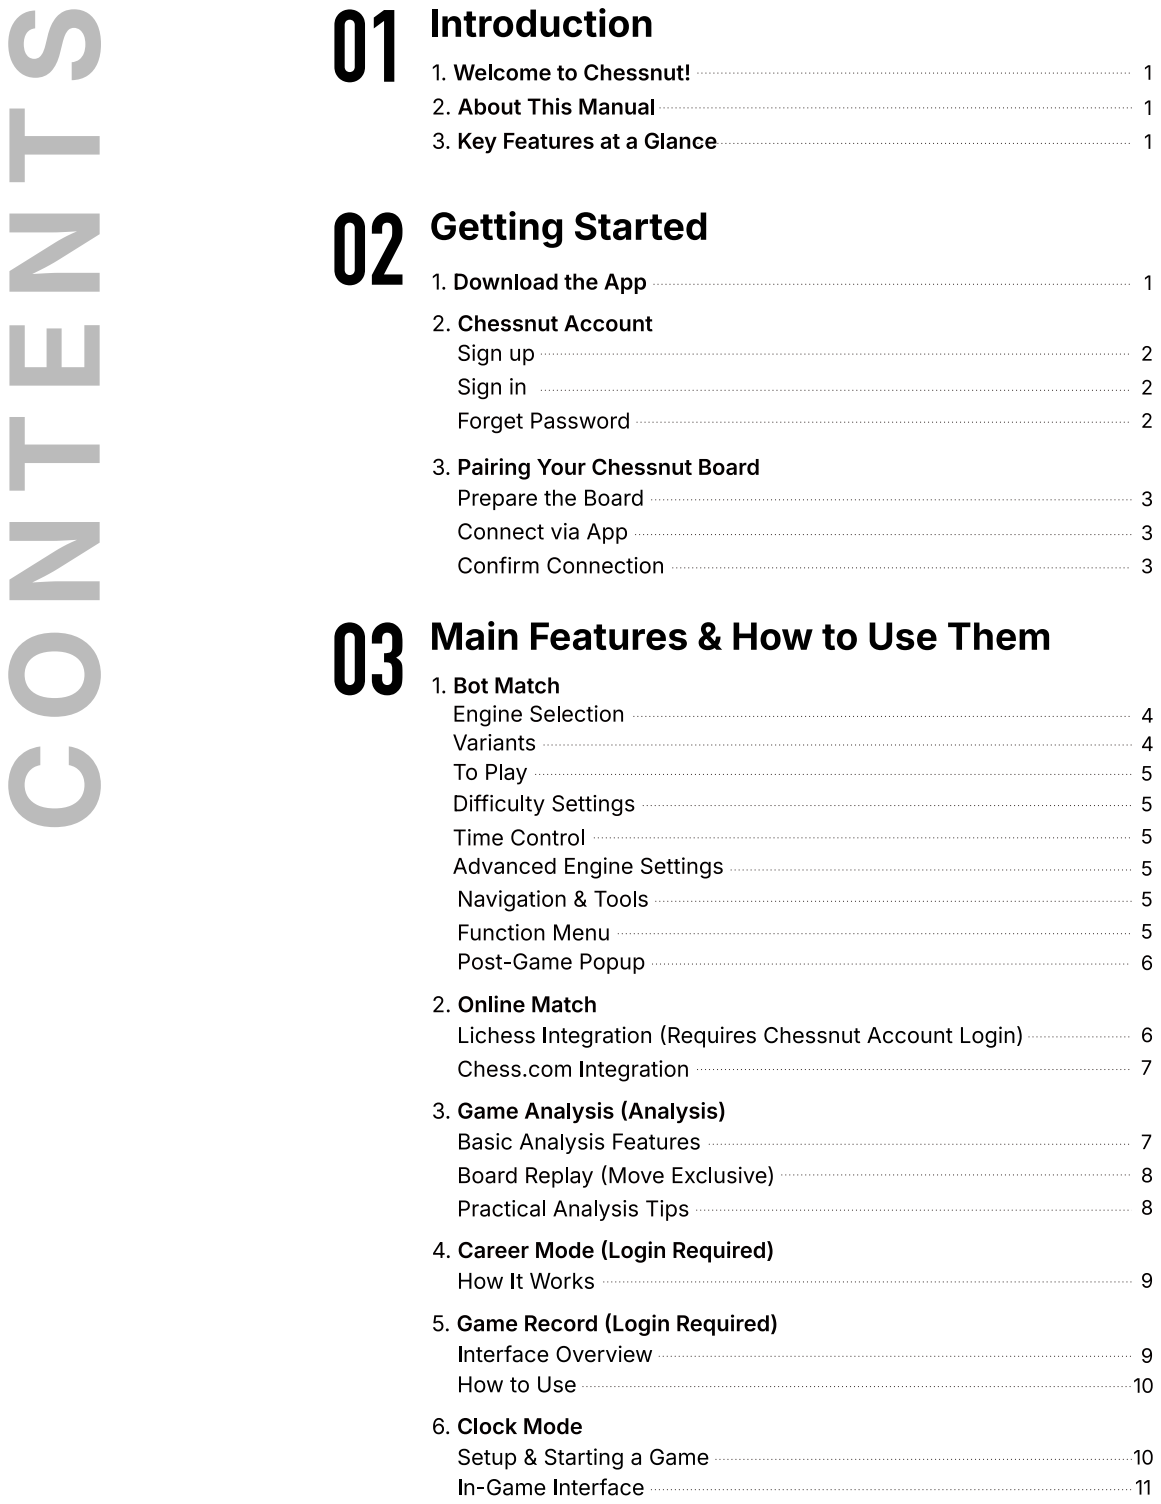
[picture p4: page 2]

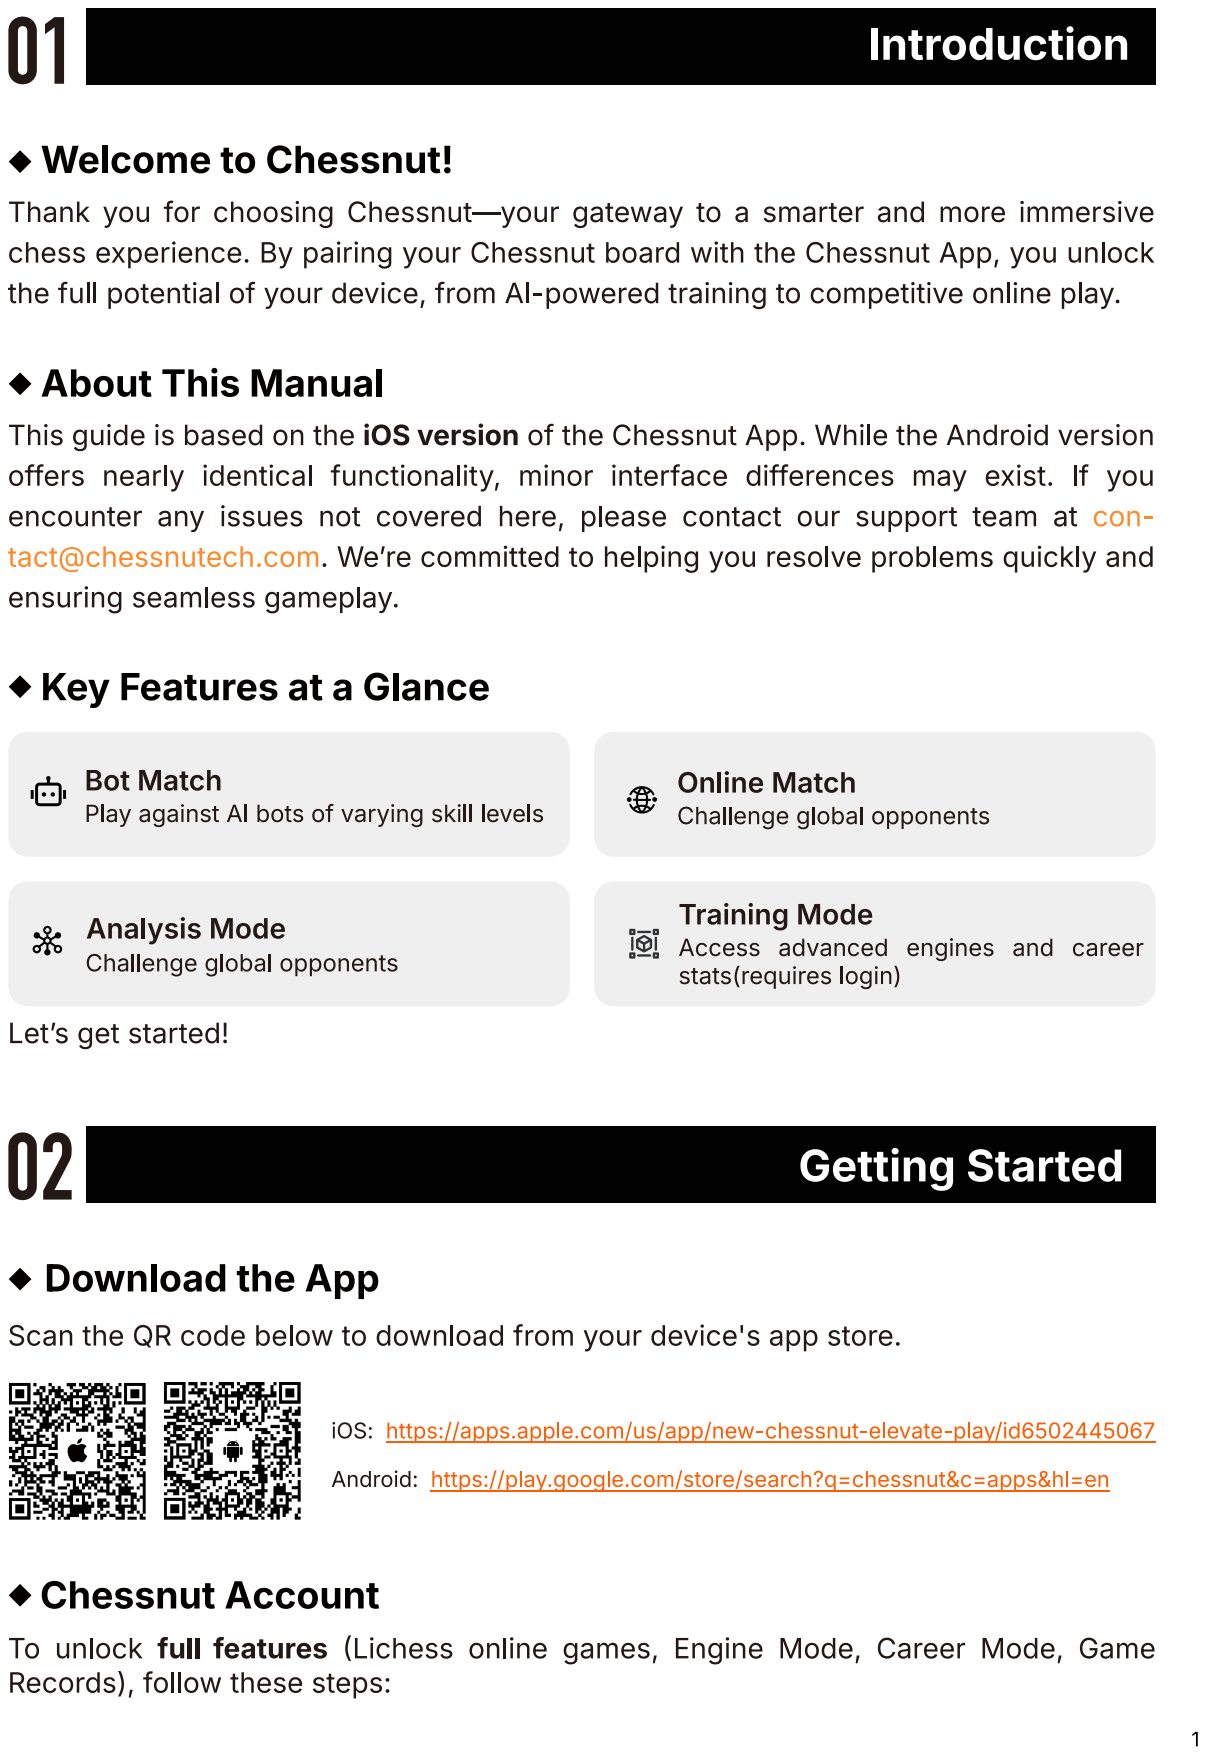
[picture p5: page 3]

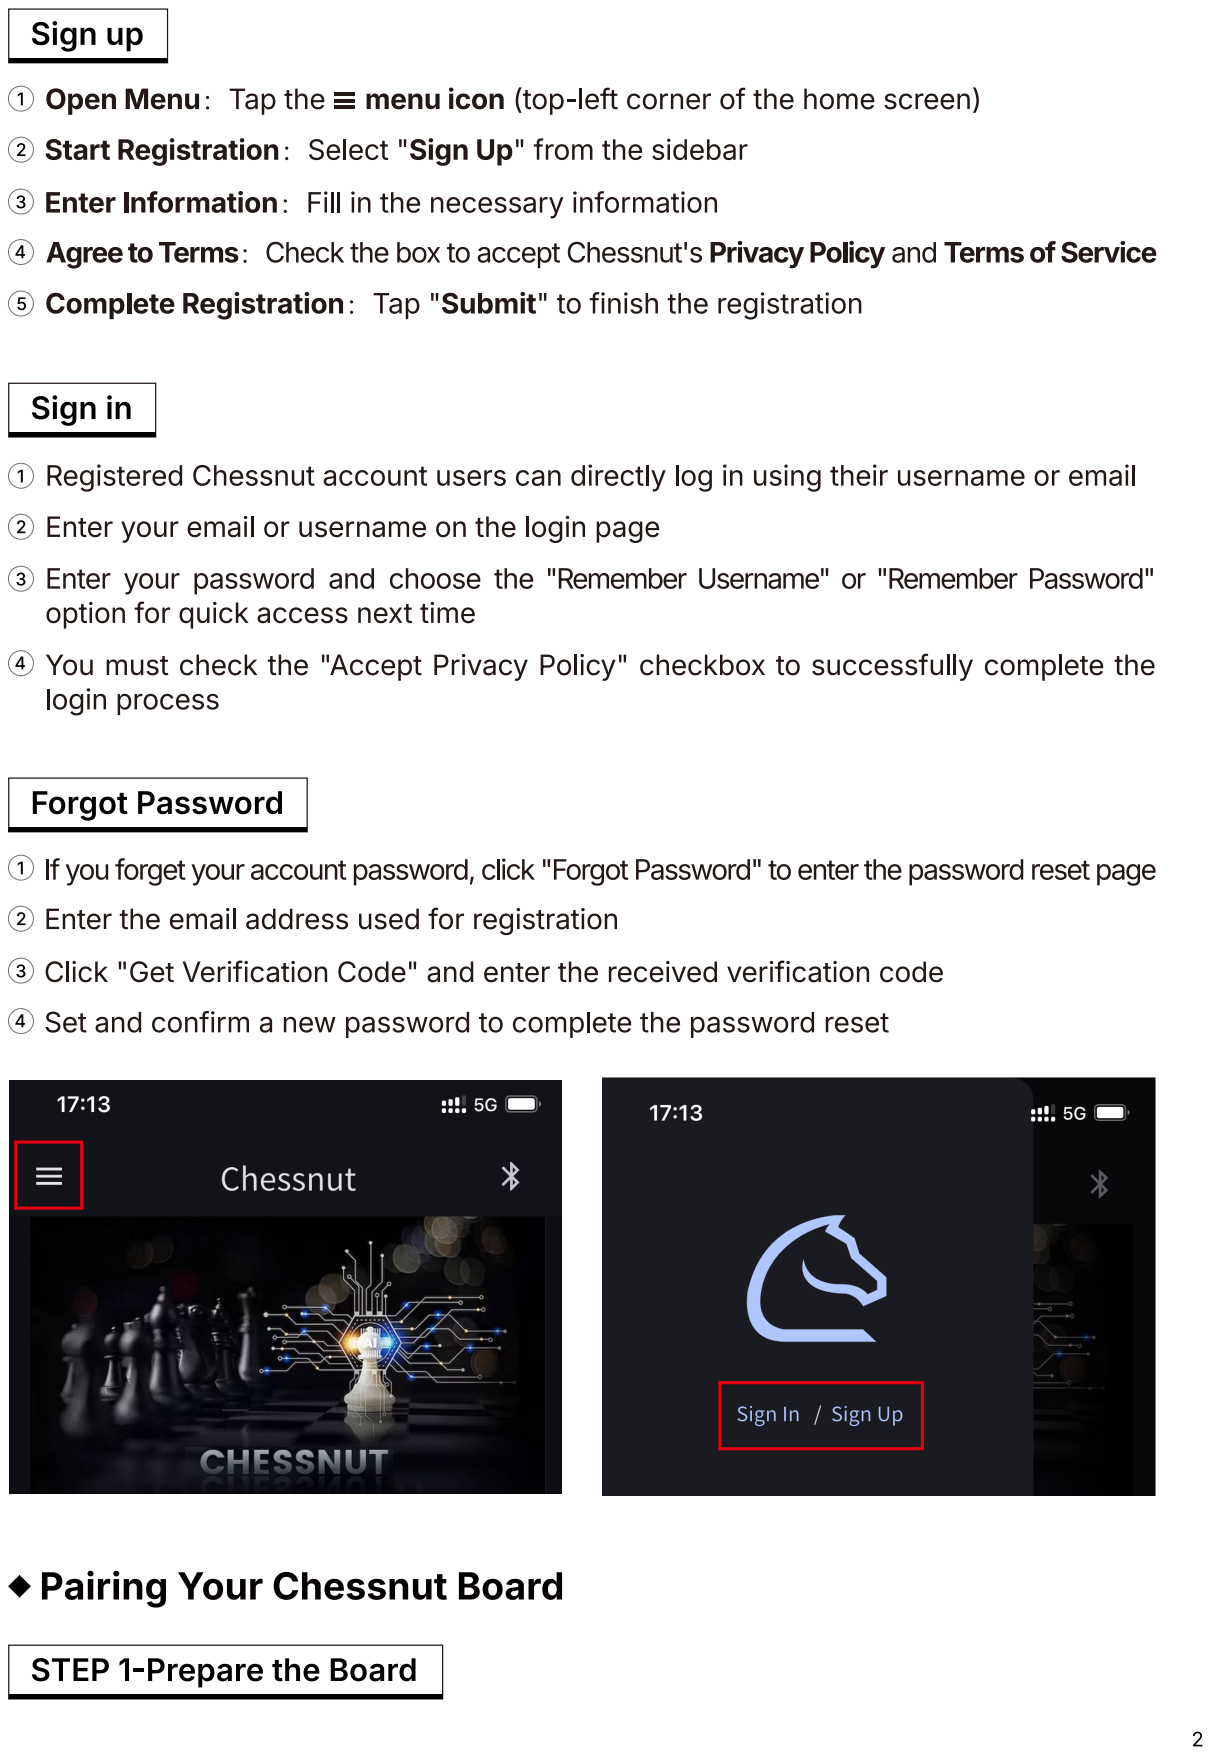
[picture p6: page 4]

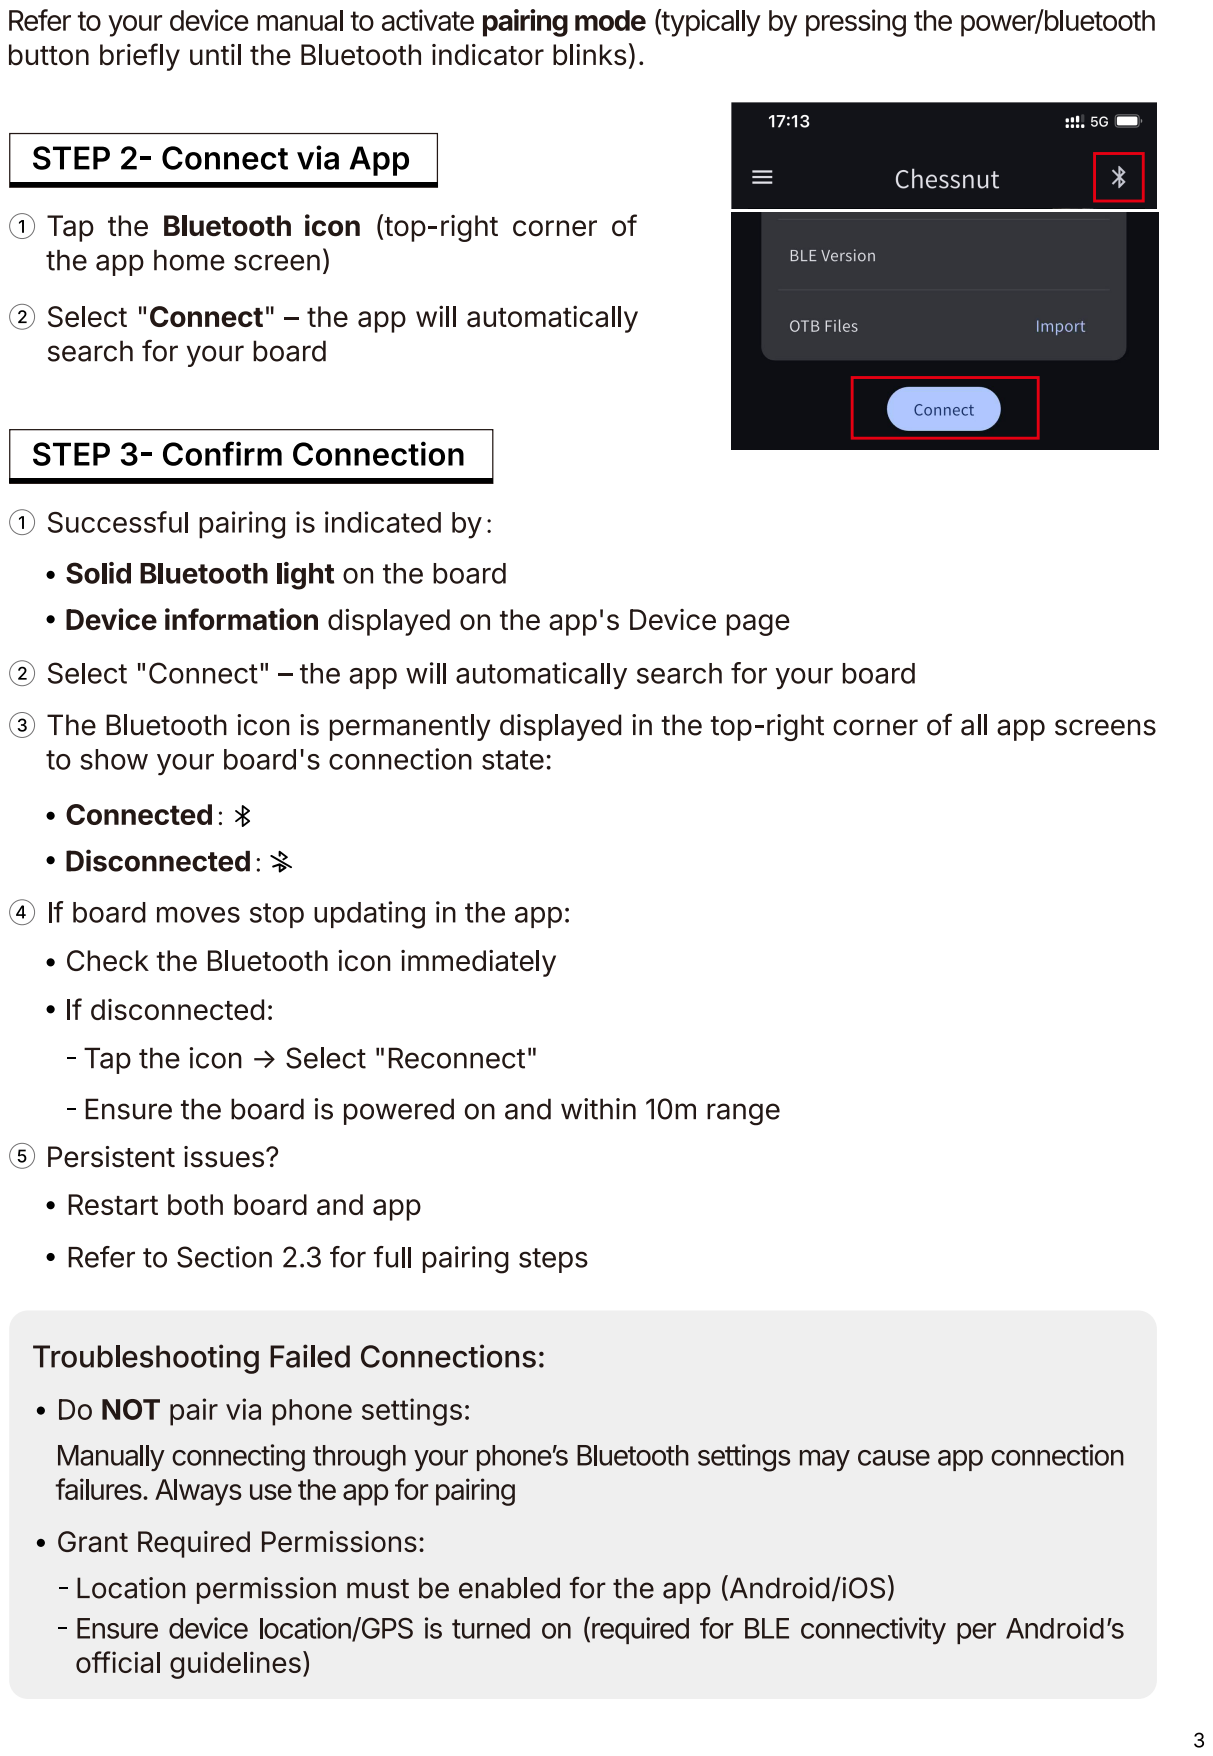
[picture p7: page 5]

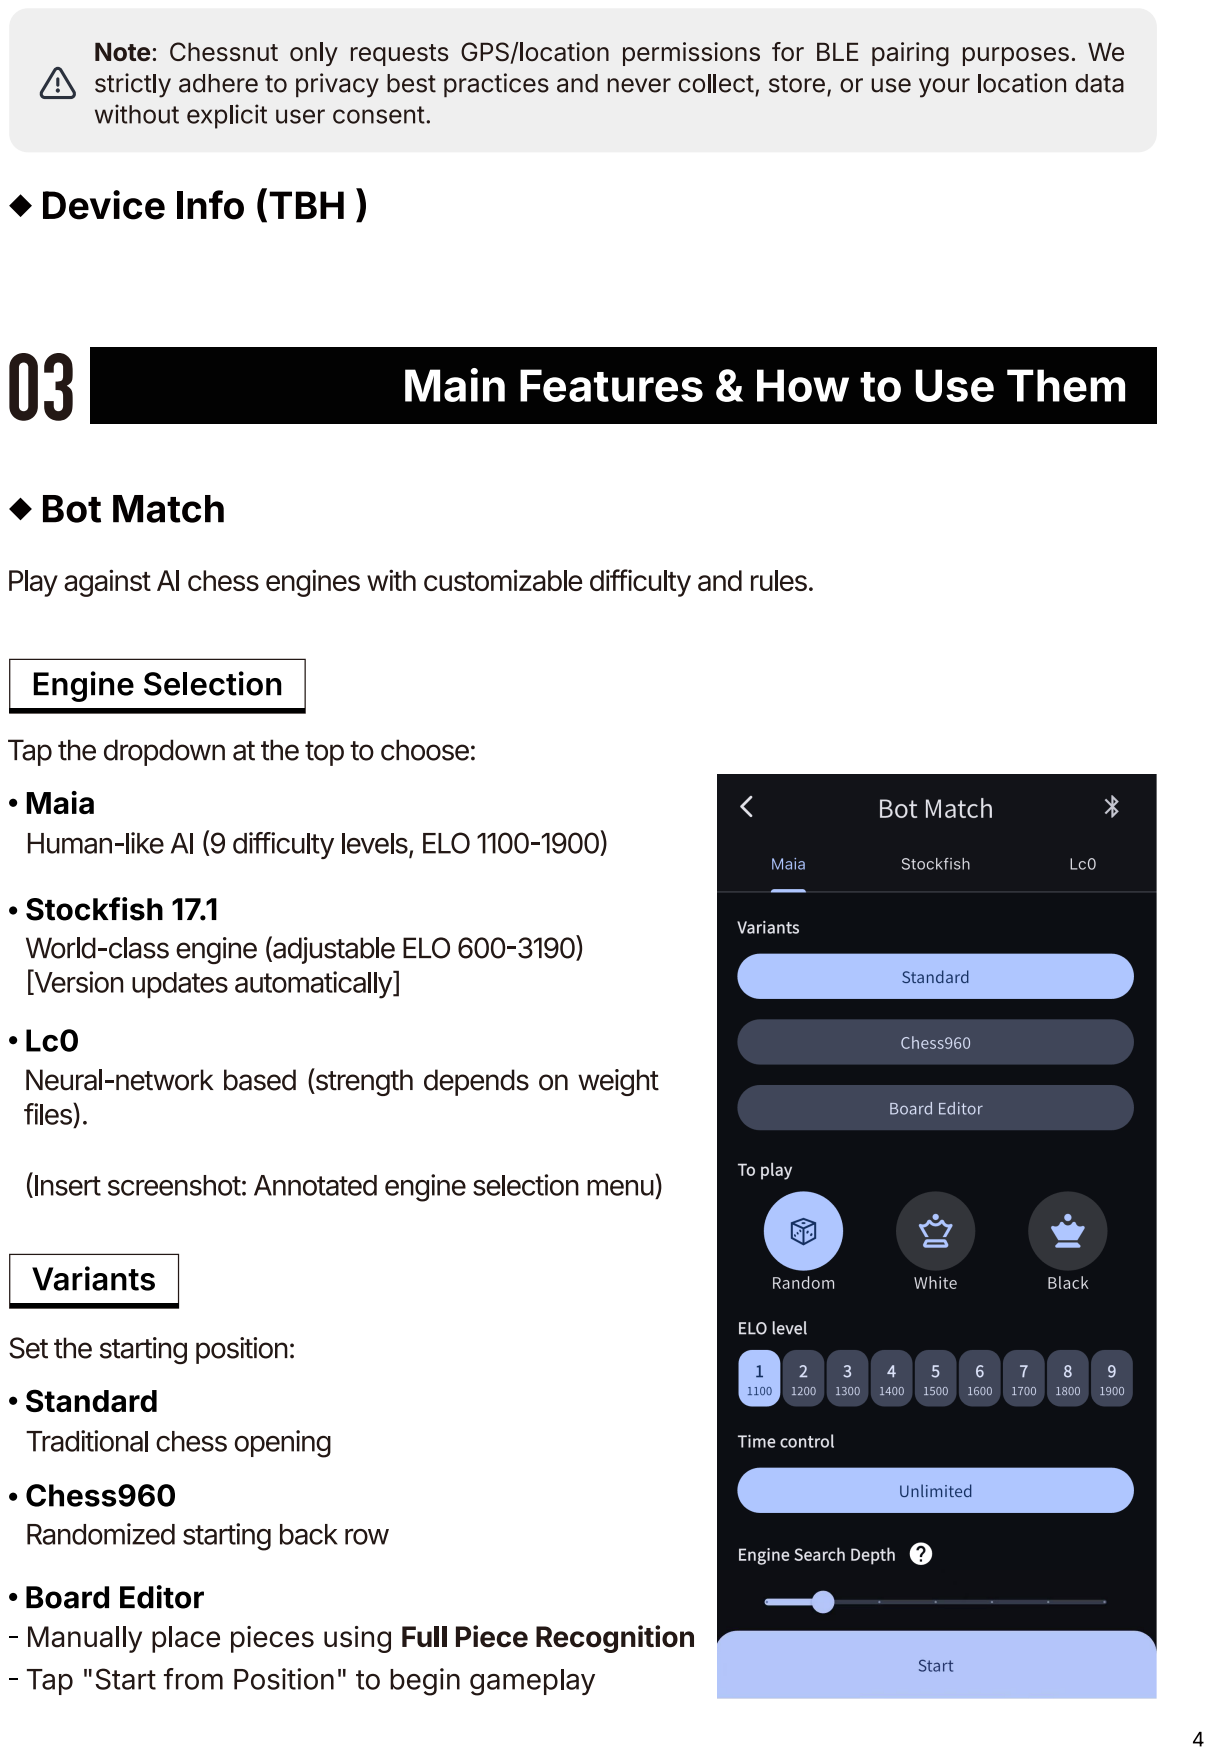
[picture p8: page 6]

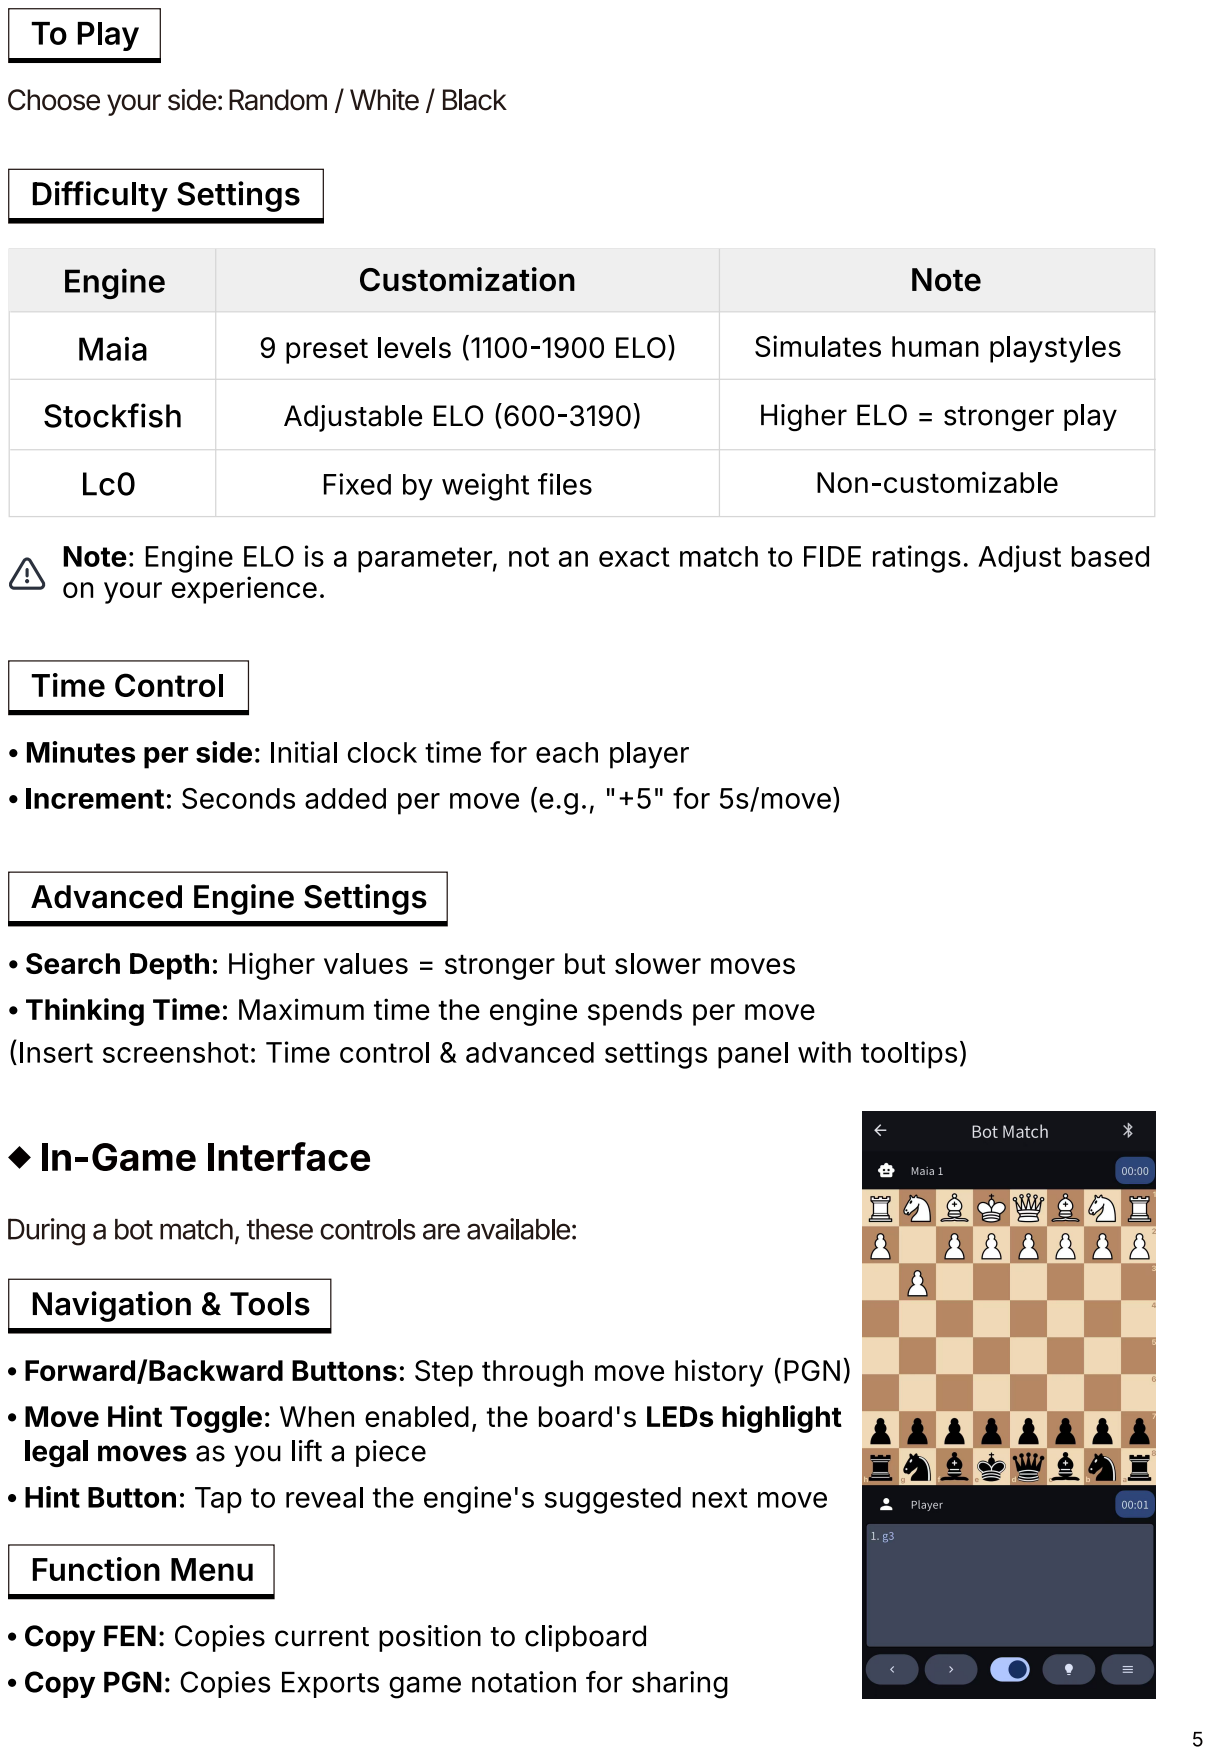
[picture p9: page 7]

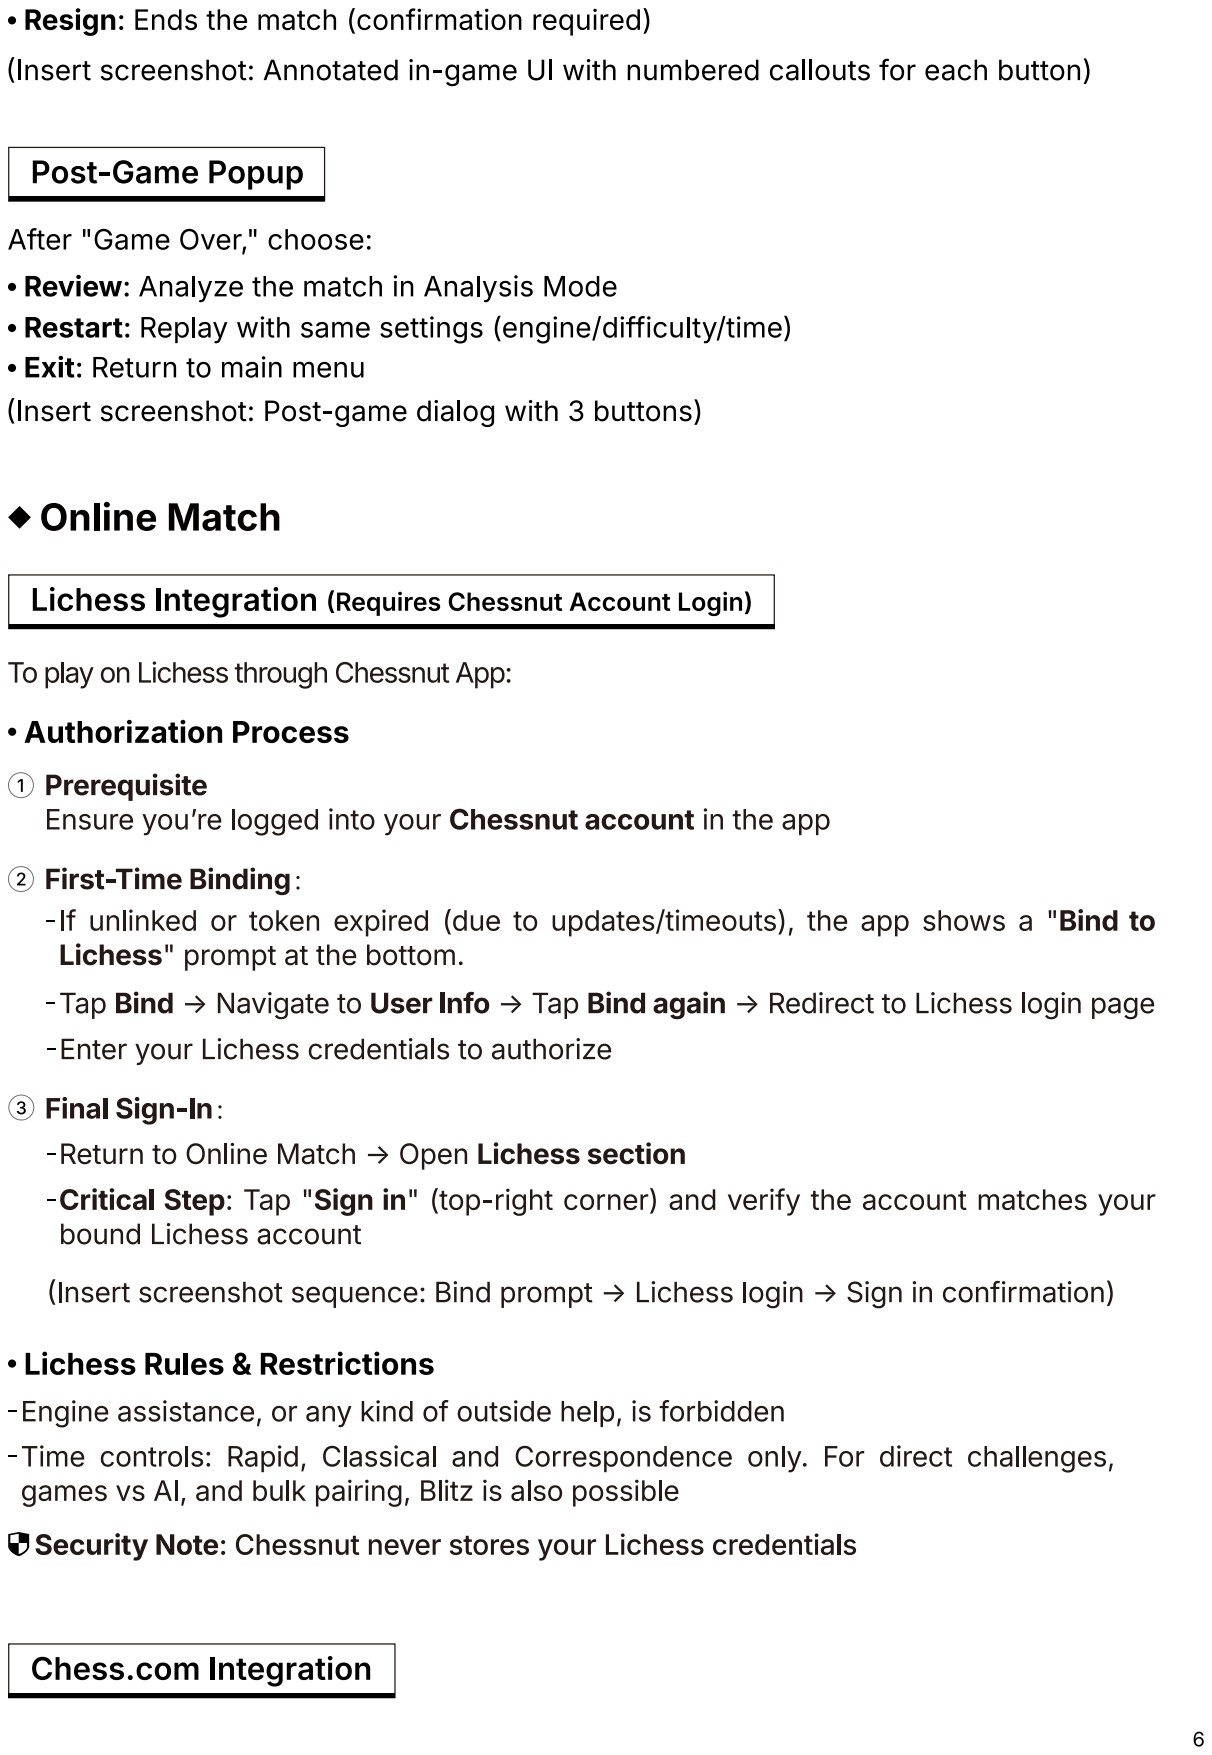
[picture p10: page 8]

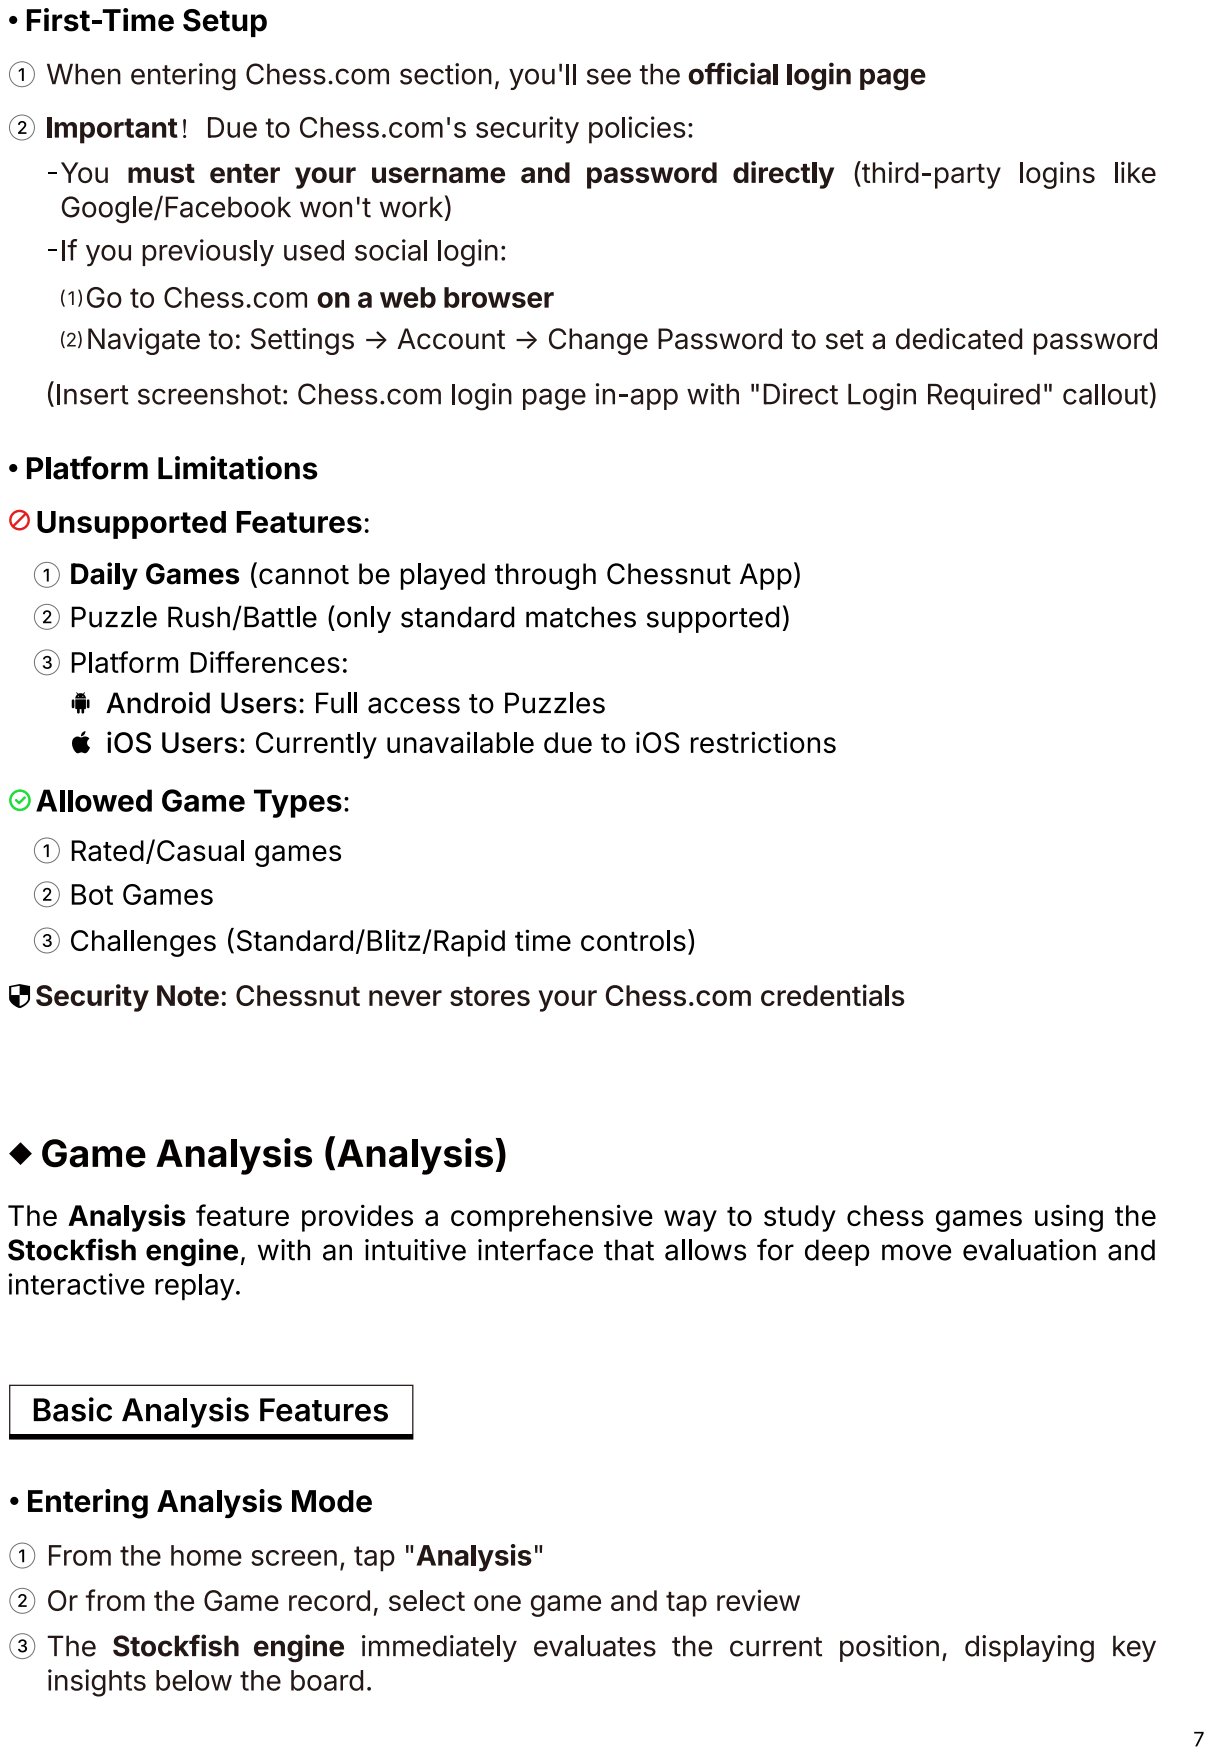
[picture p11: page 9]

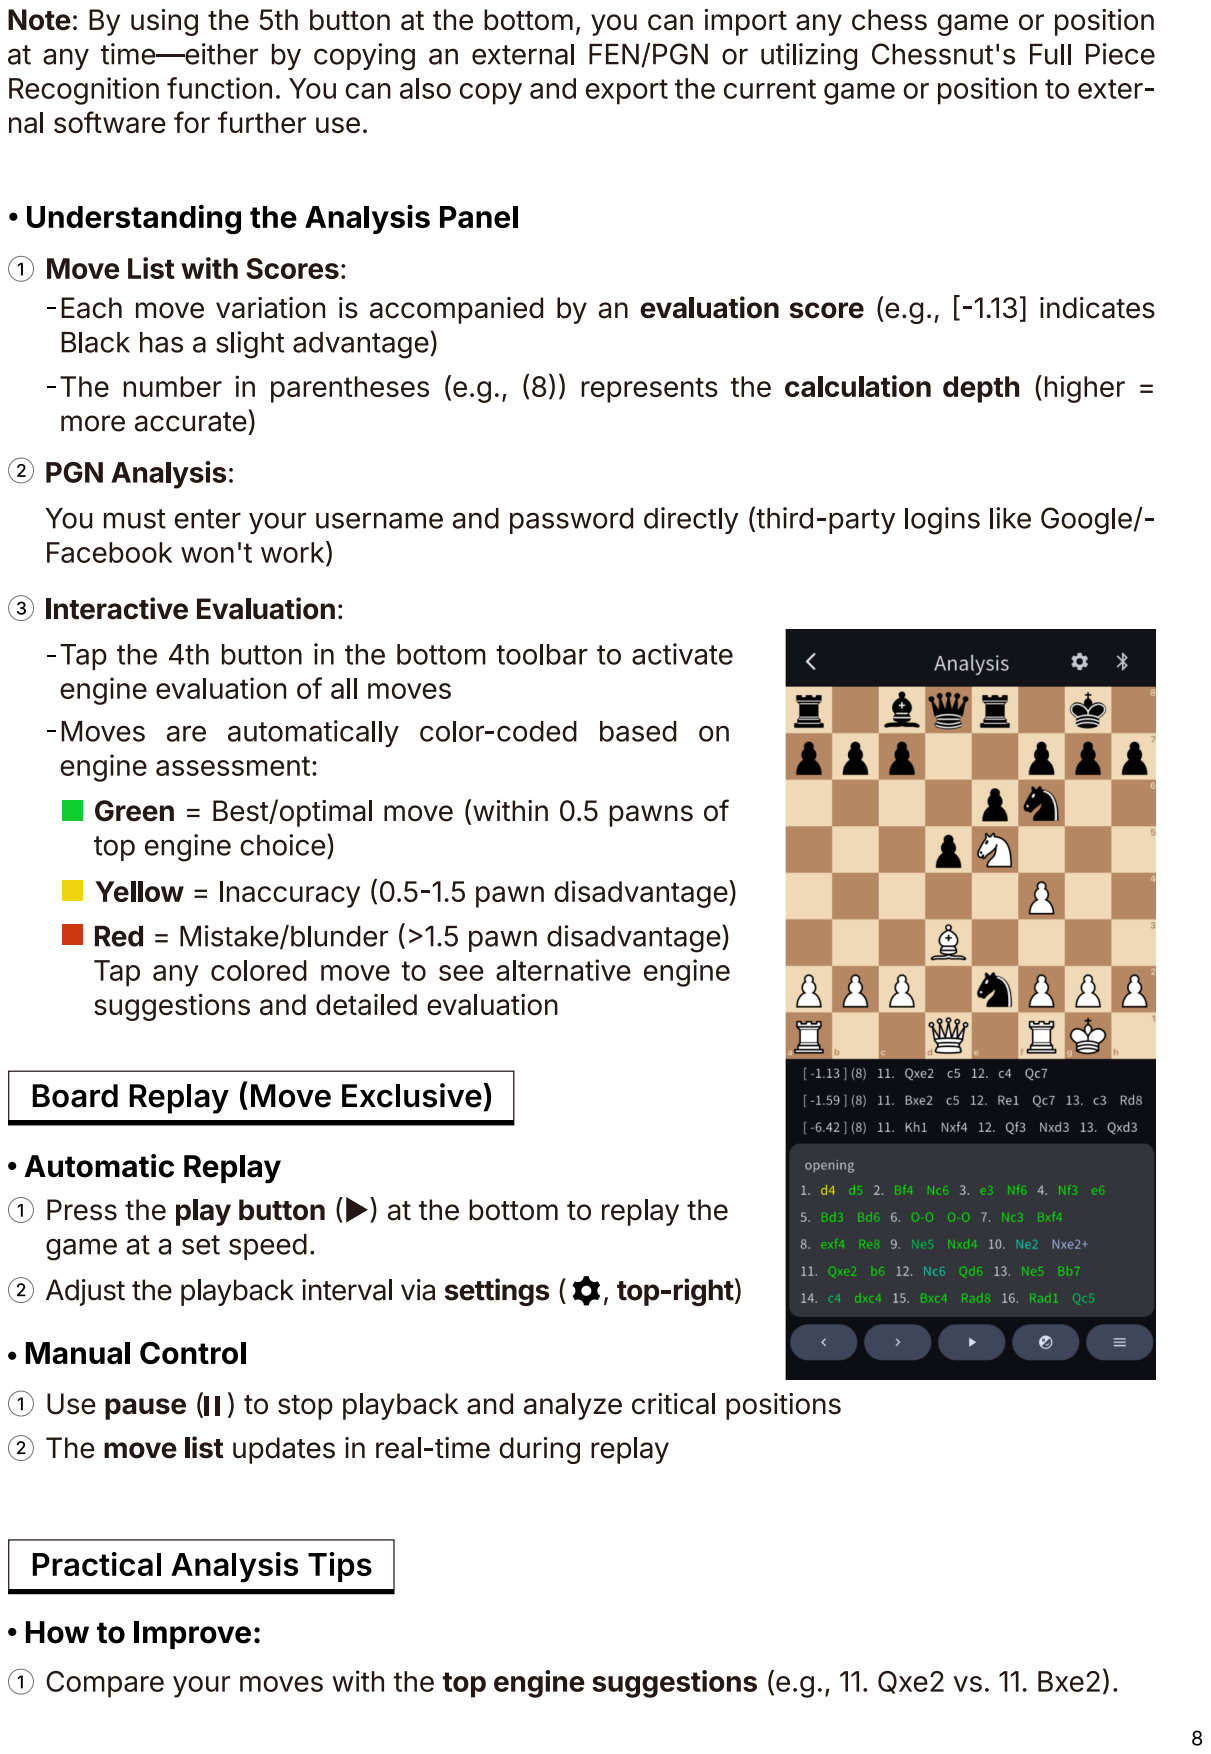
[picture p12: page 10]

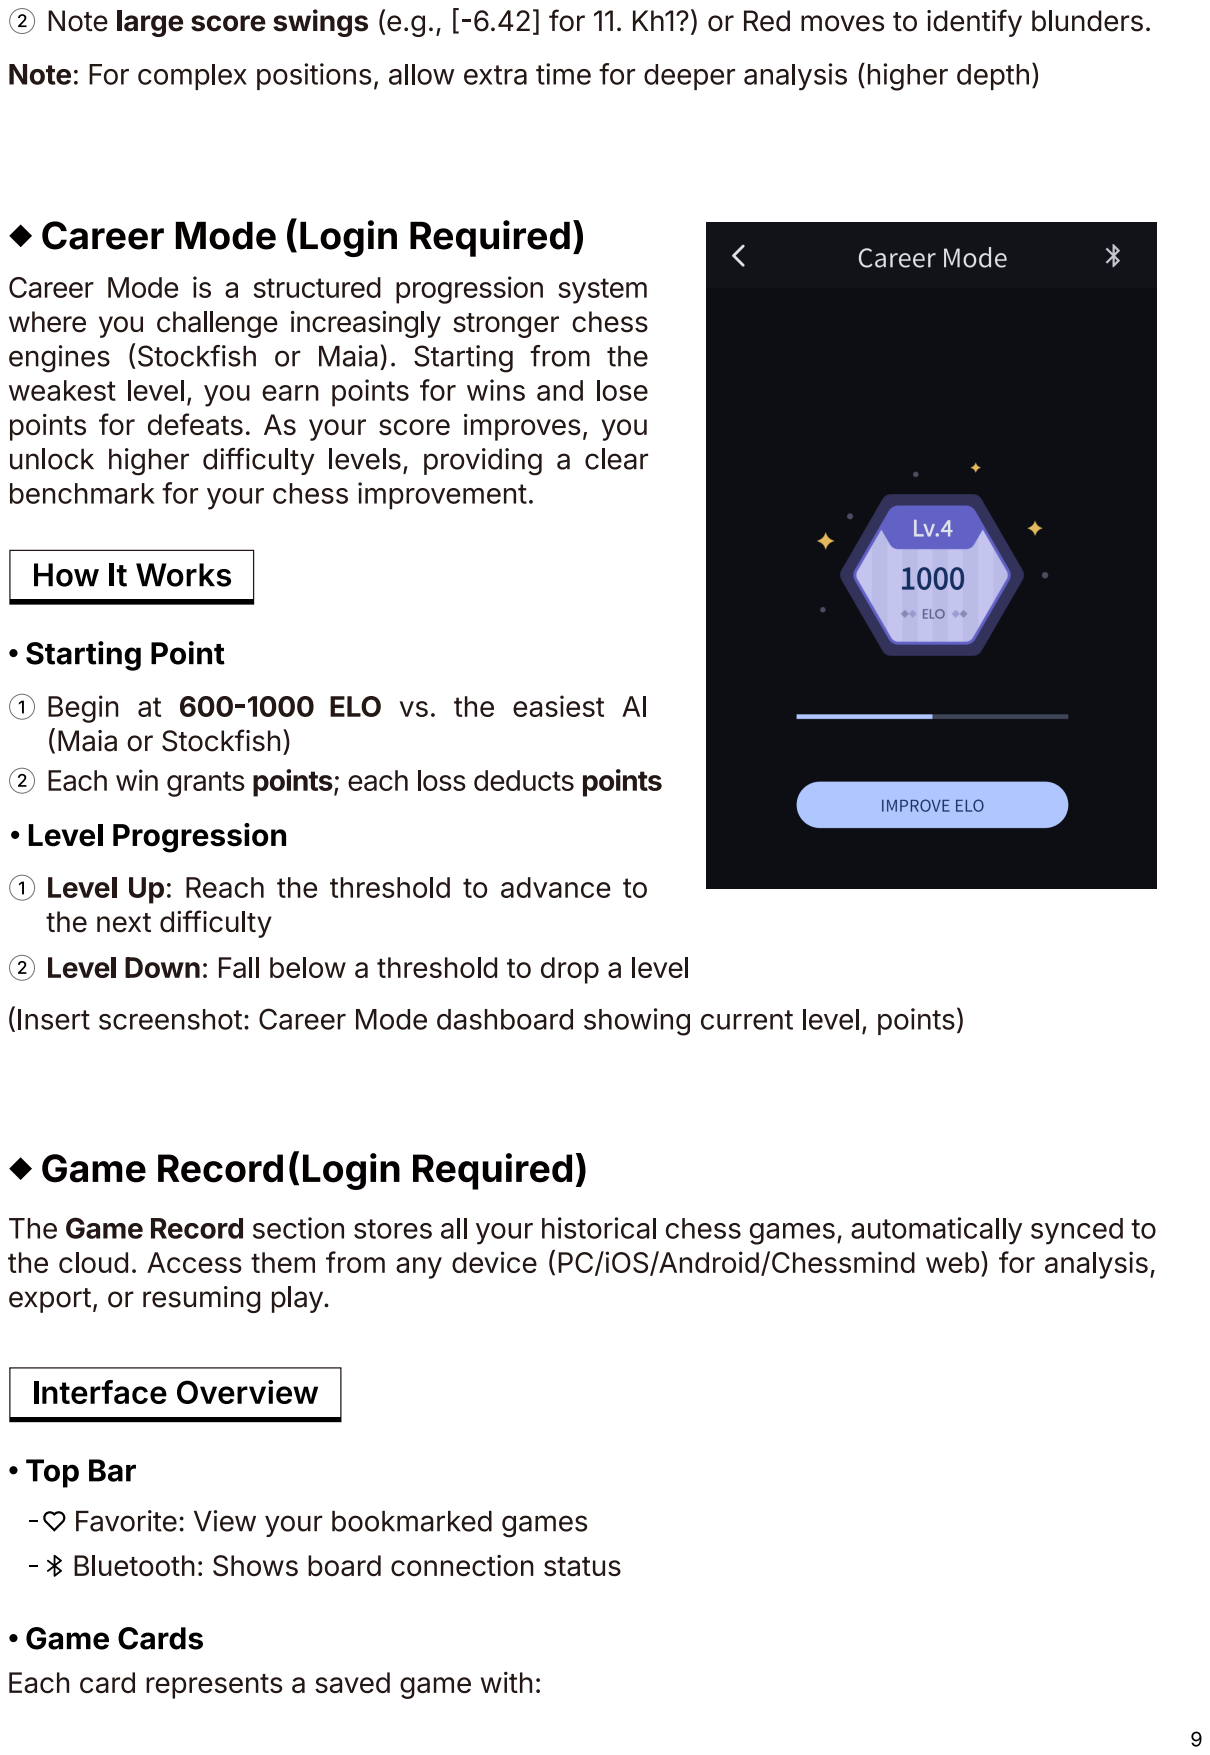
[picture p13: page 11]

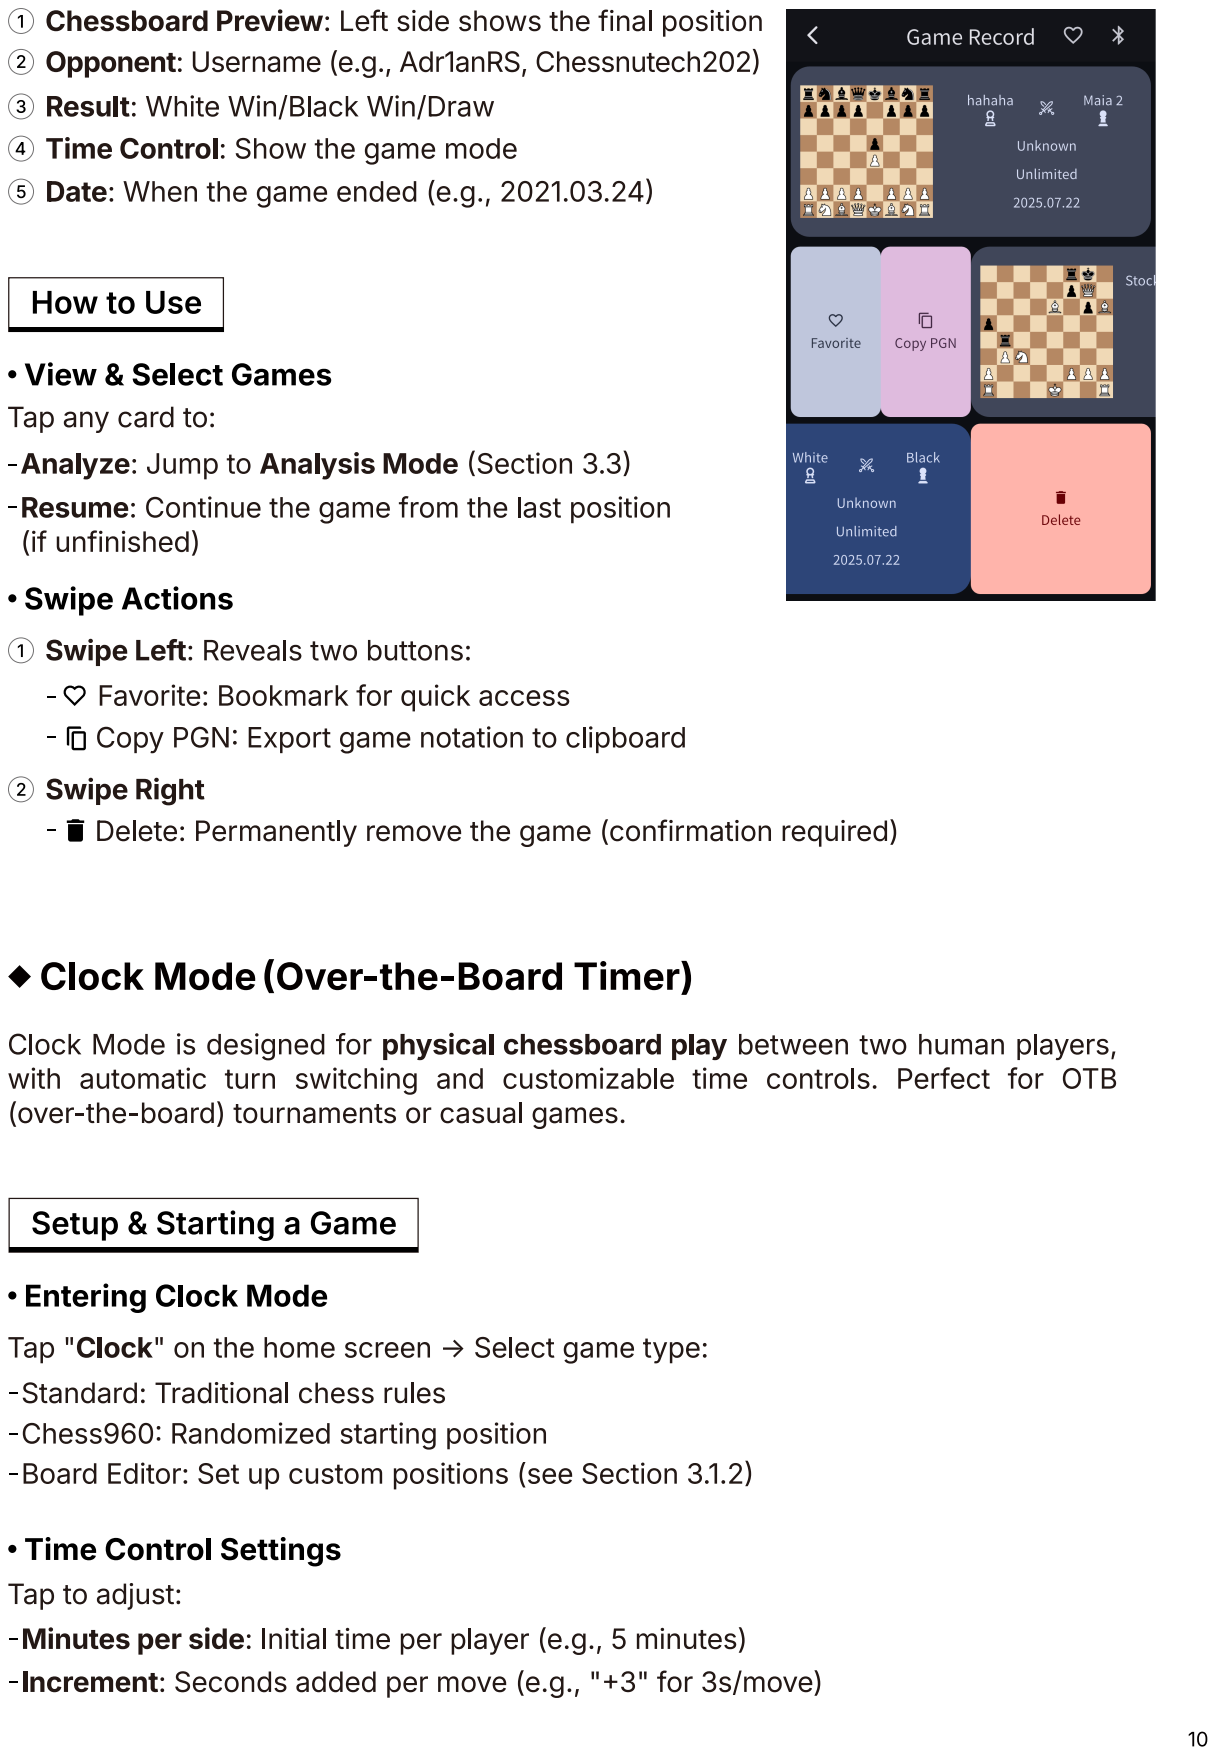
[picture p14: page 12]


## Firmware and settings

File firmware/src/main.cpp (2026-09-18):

// ============================================================
// 万象实体互动桌 - ESP32-S3 主固件
// 功能：XY电机控制 + 电磁铁 + BLE通信 + 限位保护
// ============================================================

#include <Arduino.h>
#include "config.h"
#include "motor_control.h"
#include "electromagnet.h"
#include "ble_service.h"
#include "command_parser.h"
#include "identity_grid.h"

MotorControl motor;
Electromagnet mag;
BLEService ble;
IdentityGrid identityGrid;

unsigned long lastCommandTime = 0;

// 处理BLE/串口收到的指令
void handleCommand(const std::string& command) {
    lastCommandTime = millis();
    
    auto args = CommandParser::parse(command);
    if (args.empty()) return;
    
    std::string type = CommandParser::getType(command);
    std::string response;
    
    if (type == "MOVE") {
        // MOVE,X,200,Y,-100  (相对移动，单位：步)
        long x = CommandParser::getArgInt(args, "X", 0);
        long y = CommandParser::getArgInt(args, "Y", 0);
        motor.moveRelative(x, y);
        motor.waitUntilDone();
        response = "OK,MOVE_DONE";
    }
    else if (type == "MOVEMM") {
        // MOVEMM,X,10,Y,-5  (相对移动，单位：毫米)
        double x = CommandParser::getArgInt(args, "X", 0);
        double y = CommandParser::getArgInt(args, "Y", 0);
        motor.moveRelativeMM(x, y);
        motor.waitUntilDone();
        response = "OK,MOVE_DONE";
    }
    else if (type == "GOTO") {
        // GOTO,X,1000,Y,500  (绝对移动，单位：步)
        long x = CommandParser::getArgInt(args, "X", 0);
        long y = CommandParser::getArgInt(args, "Y", 0);
        motor.moveTo(x, y);
        motor.waitUntilDone();
        response = "OK,GOTO_DONE";
    }
    else if (type == "GRID") {
        // GRID,ROW,3,COL,4  (移动到棋盘格)
        int row = CommandParser::getArgInt(args, "ROW", 0);
        int col = CommandParser::getArgInt(args, "COL", 0);
        motor.moveToGrid(row, col);
        motor.waitUntilDone();
        response = "OK,GRID_DONE";
    }
    else if (type == "PIECE") {
        // PIECE,FROMROW,3,FROMCOL,2,TOROW,5,TOCOL,4
        // 完整移动一枚互动片：移动到起点→吸合→移动到终点→释放
        int fromRow = CommandParser::getArgInt(args, "FROMROW", 0);
        int fromCol = CommandParser::getArgInt(args, "FROMCOL", 0);
        int toRow = CommandParser::getArgInt(args, "TOROW", 0);
        int toCol = CommandParser::getArgInt(args, "TOCOL", 0);
        
        if (args.size() < 9 || fromRow < 0 || fromRow > 7 || fromCol < 0 || fromCol > 7 ||
            toRow < 0 || toRow > 7 || toCol < 0 || toCol > 7) {
            response = "ERR,INVALID_PIECE";
            Serial.println(response.c_str());
            ble.notify(response);
            return;
        }
        
        motor.moveToGrid(fromRow, fromCol);
        motor.waitUntilDone();
        mag.on();
        delay(100);
        motor.moveToGrid(toRow, toCol);
        motor.waitUntilDone();
        mag.off();
        response = "OK,PIECE_DONE";
    }
    else if (type == "HOME") {
        motor.home();
        response = "OK,HOME_DONE";
    }
    else if (type == "MAG") {
        // MAG,ON 或 MAG,OFF 或 MAG,PULSE,500
        std::string action = args.size() > 1 ? args[1] : "";
        if (action == "ON") {
            mag.on();
            response = "OK,MAG_ON";
        } else if (action == "OFF") {
            mag.off();
            response = "OK,MAG_OFF";
        } else if (action == "PULSE") {
            int ms = args.size() > 2 ? std::stol(args[2]) : 300;
            mag.pulse(ms);
            response = "OK,MAG_PULSE";
        }
    }
    else if (type == "SPEED") {
        // SPEED,1500
        double speed = args.size() > 1 ? std::stod(args[1]) : MAX_SPEED;
        motor.setSpeed(speed);
        response = "OK,SPEED_SET";
    }
    else if (type == "STATUS" || type == "STATUS?") {
        char buf[128];
        snprintf(buf, sizeof(buf), "STATUS,X:%ld,Y:%ld,MAG:%s,READY",
                 motor.getXPosition(), motor.getYPosition(),
                 mag.isOn() ? "ON" : "OFF");
        response = buf;
    }
    else if (type == "ID_SCAN" || type == "SNAPSHOT?") {
        // 首版逐格读取 DS2431/DS2401 ROM。通道号按棋盘布线表映射到具体格位。
        // 空格返回 EMPTY，CRC 错误返回 CRC_ERROR，避免把坏读数当成棋子。
        for (uint8_t channel = 0; channel < identityGrid.channelCount(); ++channel) {
            IdentityReading reading = identityGrid.readChannel(channel);
            if (!reading.present) {
                response = "IDSCAN,CH," + std::to_string(channel) + ",EMPTY";
            } else if (!reading.crc_ok) {
                response = "IDSCAN,CH," + std::to_string(channel) + ",CRC_ERROR";
            } else if (!reading.supported_family) {
                response = "IDSCAN,CH," + std::to_string(channel) + ",UNSUPPORTED_FAMILY";
            } else {
                response = "IDSCAN,CH," + std::to_string(channel) + ",UID," +
                           std::string(identityGrid.formatUid(reading.uid).c_str());
            }
            Serial.println(response.c_str());
            ble.notify(response);
        }
        response = "OK,ID_SCAN_DONE";
    }
    else if (type == "ENABLE") {
        motor.enable();
        response = "OK,ENABLED";
    }
    else if (type == "DISABLE") {
        motor.disable();
        response = "OK,DISABLED";
    }
    else if (type == "STOP") {
        motor.stop();
        mag.off();
        response = "OK,STOPPED";
    }
    else if (type == "HELP") {
        response = "COMMANDS:ID_SCAN,SNAPSHOT?,MOVE,MOVEMM,GOTO,GRID,PIECE,HOME,MAG,SPEED,STATUS,ENABLE,DISABLE,STOP";
    }
    else {
        response = "ERR,UNKNOWN_CMD";
    }
    
    // 发送响应
    Serial.println(response.c_str());
    ble.notify(response);
}

void setup() {
    Serial.begin(115200);
    delay(1000);
    
    Serial.println("\n========================================");
    Serial.println("  万象实体互动桌 - ESP32-S3 固件");
    Serial.println("  版本: v1.0");
    Serial.println("========================================");
    
    // 初始化各模块
    motor.begin();
    mag.begin();
    identityGrid.begin();
    ble.begin(handleCommand);
    
    // 上电自动回零（可选，注释掉可跳过）
    // motor.home();
    
    Serial.println("[System] 初始化完成，等待指令...");
    Serial.println("[System] 输入 HELP 查看可用指令；ID_SCAN 扫描身份格位");
}

void loop() {
    // 电机非阻塞运行
    motor.run();
    
    // 电磁铁过热保护
    mag.tick();
    
    // 串口指令（调试用）
    if (Serial.available()) {
        String cmd = Serial.readStringUntil('\n');
        cmd.trim();
        if (cmd.length() > 0) {
            handleCommand(cmd.c_str());
        }
    }
    
    // 指令超时保护：长时间无指令自动断电电机
    if (motor.isRunning() == false && 
        millis() - lastCommandTime > COMMAND_TIMEOUT_MS &&
        lastCommandTime > 0) {
        // 电机失能省电（不影响电磁铁）
        // motor.disable();  // 如需启用超时断电，取消注释
    }
    
    delay(1);
}

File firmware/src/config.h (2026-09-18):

#ifndef CONFIG_H
#define CONFIG_H

// ============================================================
// 万象实体互动桌 - 配置文件
// 根据你的实际接线修改这里的引脚定义
// ============================================================

// ---------- 电机引脚 ----------
#define X_DIR_PIN   13
#define X_STEP_PIN  14
#define X_EN_PIN    15
#define Y_DIR_PIN   26
#define Y_STEP_PIN  27
#define Y_EN_PIN    25

// ---------- 电磁铁引脚 ----------
#define MAG_PIN     32   // PWM输出，经MOS管控制电磁铁

// ---------- 限位开关引脚 ----------
// 接线：一端接GPIO，一端接GND（使用内部上拉）
#define X_LIMIT_MIN 34   // X轴左限位
#define X_LIMIT_MAX 35   // X轴右限位
#define Y_LIMIT_MIN 36   // Y轴前限位
#define Y_LIMIT_MAX 39   // Y轴后限位

// ---------- 蜂鸣器（可选） ----------
#define BUZZER_PIN  4

// ---------- 无视觉身份识别（DS2431/DS2401 + 74HC4067） ----------
// 74HC4067 的 EN 为低有效。首轮接 2×2 或 4×4，未使用通道保持空。
// N8R8 开发板可能占用部分高编号 GPIO，采购后按实际丝印复核并修改。
#define ID_ONEWIRE_PIN  5
#define ID_MUX_S0_PIN   6
#define ID_MUX_S1_PIN   7
#define ID_MUX_S2_PIN   8
#define ID_MUX_S3_PIN   9
#define ID_MUX_EN_PIN   10
#define ID_GRID_CHANNELS 16
#define ID_SCAN_RETRIES  3
#define ID_SETTLE_MS     2

// ---------- 机械参数（需标定后修改） ----------
#define STEPS_PER_MM    80.0    // 每毫米步数（同步带+20齿同步轮约80）
#define MAX_SPEED       2000    // 最大速度（步/秒）
#define ACCELERATION    1500    // 加速度（步/秒²）
#define TRAVEL_MM_X     250     // X轴行程(mm)
#define TRAVEL_MM_Y     250     // Y轴行程(mm)

// ---------- 棋盘参数 ----------
#define GRID_SIZE_MM    30.0    // 棋盘格距(mm)
#define GRID_COUNT      8       // 棋盘格数（8×8）

// ---------- 电磁铁参数 ----------
#define MAG_PWM_FREQ    1000    // PWM频率
#define MAG_PWM_CHANNEL 0       // LEDC通道
#define MAG_HOLD_TIME_MS 30000  // 连续吸合最大时间（过热保护）

// ---------- BLE参数 ----------
#define BLE_DEVICE_NAME "WanxiangTable"
#define BLE_SERVICE_UUID        "0000ffe0-0000-1000-8000-00805f9b34fb"
#define BLE_CHARACTERISTIC_UUID "0000ffe1-0000-1000-8000-00805f9b34fb"

// ---------- 安全参数 ----------
#define COMMAND_TIMEOUT_MS  10000   // 指令超时（无指令自动断电电机）
#define DEBOUNCE_MS         10      // 限位开关消抖

#endif // CONFIG_H

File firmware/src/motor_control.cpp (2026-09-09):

#include "motor_control.h"
#include <Arduino.h>

MotorControl::MotorControl()
    : _stepperX(AccelStepper::DRIVER, X_STEP_PIN, X_DIR_PIN),
      _stepperY(AccelStepper::DRIVER, Y_STEP_PIN, Y_DIR_PIN),
      _homed(false), _enabled(false) {}

void MotorControl::begin() {
    // 初始化引脚
    pinMode(X_EN_PIN, OUTPUT);
    pinMode(Y_EN_PIN, OUTPUT);
    pinMode(X_LIMIT_MIN, INPUT_PULLUP);
    pinMode(X_LIMIT_MAX, INPUT_PULLUP);
    pinMode(Y_LIMIT_MIN, INPUT_PULLUP);
    pinMode(Y_LIMIT_MAX, INPUT_PULLUP);
    
    // 失能电机（低电平使能，所以HIGH=失能）
    digitalWrite(X_EN_PIN, HIGH);
    digitalWrite(Y_EN_PIN, HIGH);
    
    // 设置电机参数
    _stepperX.setMaxSpeed(MAX_SPEED);
    _stepperX.setAcceleration(ACCELERATION);
    _stepperY.setMaxSpeed(MAX_SPEED);
    _stepperY.setAcceleration(ACCELERATION);
    
    Serial.println("[Motor] 初始化完成");
}

void MotorControl::enable() {
    digitalWrite(X_EN_PIN, LOW);
    digitalWrite(Y_EN_PIN, LOW);
    _enabled = true;
    Serial.println("[Motor] 电机使能");
}

void MotorControl::disable() {
    digitalWrite(X_EN_PIN, HIGH);
    digitalWrite(Y_EN_PIN, HIGH);
    _enabled = false;
    Serial.println("[Motor] 电机失能");
}

void MotorControl::moveRelative(long xSteps, long ySteps) {
    if (!_enabled) enable();
    _stepperX.move(xSteps);
    _stepperY.move(ySteps);
}

void MotorControl::moveRelativeMM(double xMm, double yMm) {
    moveRelative((long)(xMm * STEPS_PER_MM), (long)(yMm * STEPS_PER_MM));
}

void MotorControl::moveTo(long xPos, long yPos) {
    if (!_enabled) enable();
    _stepperX.moveTo(xPos);
    _stepperY.moveTo(yPos);
}

void MotorControl::moveToGrid(int row, int col) {
    // 棋盘中心为原点，转换为毫米坐标
    double centerOffset = (GRID_COUNT - 1) * GRID_SIZE_MM / 2.0;
    double xMm = col * GRID_SIZE_MM - centerOffset;
    double yMm = row * GRID_SIZE_MM - centerOffset;
    moveTo((long)(xMm * STEPS_PER_MM), (long)(yMm * STEPS_PER_MM));
}

bool MotorControl::home() {
    Serial.println("[Motor] 开始回零...");
    if (!_enabled) enable();
    
    const long homeSpeed = 500;   // 回零速度
    const long slowSpeed = 200;   // 慢速回零速度
    
    // ---- X轴回零 ----
    _stepperX.setMaxSpeed(homeSpeed);
    _stepperX.moveTo(-100000);  // 往负方向一直走
    
    while (digitalRead(X_LIMIT_MIN) == HIGH) {
        _stepperX.run();
        if (digitalRead(X_LIMIT_MIN) == LOW) break;
    }
    _stepperX.stop();
    _stepperX.setCurrentPosition(0);
    
    // 退一点再慢速碰一次（提高精度）
    _stepperX.setMaxSpeed(slowSpeed);
    _stepperX.move(200);
    waitUntilDone();
    _stepperX.moveTo(-100000);
    while (digitalRead(X_LIMIT_MIN) == HIGH) {
        _stepperX.run();
    }
    _stepperX.stop();
    _stepperX.setCurrentPosition(0);
    
    // ---- Y轴回零 ----
    _stepperY.setMaxSpeed(homeSpeed);
    _stepperY.moveTo(-100000);
    while (digitalRead(Y_LIMIT_MIN) == HIGH) {
        _stepperY.run();
    }
    _stepperY.stop();
    _stepperY.setCurrentPosition(0);
    
    _stepperY.setMaxSpeed(slowSpeed);
    _stepperY.move(200);
    waitUntilDone();
    _stepperY.moveTo(-100000);
    while (digitalRead(Y_LIMIT_MIN) == HIGH) {
        _stepperY.run();
    }
    _stepperY.stop();
    _stepperY.setCurrentPosition(0);
    
    // 恢复正常速度
    _stepperX.setMaxSpeed(MAX_SPEED);
    _stepperY.setMaxSpeed(MAX_SPEED);
    
    _homed = true;
    Serial.println("[Motor] 回零完成");
    return true;
}

void MotorControl::waitUntilDone() {
    while (_stepperX.isRunning() || _stepperY.isRunning()) {
        _stepperX.run();
        _stepperY.run();
    }
}

void MotorControl::run() {
    _stepperX.run();
    _stepperY.run();
}

void MotorControl::stop() {
    _stepperX.stop();
    _stepperY.stop();
}

long MotorControl::getXPosition() { return _stepperX.currentPosition(); }
long MotorControl::getYPosition() { return _stepperY.currentPosition(); }
double MotorControl::getXMM() { return _stepperX.currentPosition() / STEPS_PER_MM; }
double MotorControl::getYMM() { return _stepperY.currentPosition() / STEPS_PER_MM; }
bool MotorControl::isRunning() { return _stepperX.isRunning() || _stepperY.isRunning(); }

void MotorControl::setSpeed(double speed) {
    _stepperX.setMaxSpeed(speed);
    _stepperY.setMaxSpeed(speed);
}

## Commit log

2026-09-09 init project
    [BOM.csv, legacy_BOM.csv, 第一批采购清单.csv]
2026-09-10 切换无视觉身份棋盘方案并加入扫描固件
    [三个月无视觉首批采购清单.csv]
2026-09-10 补充无视觉身份扫描协议样例
2026-09-18 918.增加器件条件约束，汇报目录
    [三个月无视觉首批采购清单.csv, 第一批采购清单.csv]
